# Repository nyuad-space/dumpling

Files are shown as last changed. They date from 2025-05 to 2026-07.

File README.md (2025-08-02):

## Hardware Errata v1 (2025)

- Pull down Boot1 instead of floating. For booting F405 with DFU, hold down the 3rd reset button.
- SWD TagConnect: Layout is too close to XT30 or M.2 sockets and connector is difficult to source.
- DRC check (recheck unconnected items).
- Look out for "x"ed POS in the BOM file. May have been accidentally toggled off.
- Reset button is too small & hard to reach
- Vertical USB is less stress-tolerant (pulls on solder)
- STM32F411 DFU bootloading error
- Check forward current rating for Schottky diodes.
- Consider using more current sensors i.e. Measure current draw from each board, from VIN total etc.
- Add in extra LEDs, buttons, etc. for extra functions/debugging in the future
- Unless saving space is a priority, consider using 0603 instead of 0402 for easier potential fixes
- Misc. Consider a more impact-tolerant casing to protect board upon landing

# Data Dumpling
<p float="left">
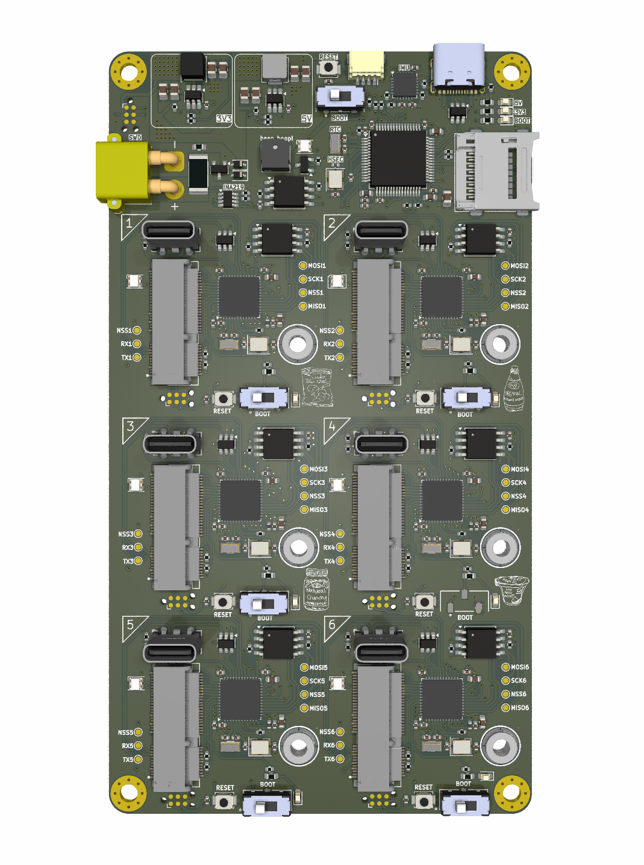
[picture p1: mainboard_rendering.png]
  
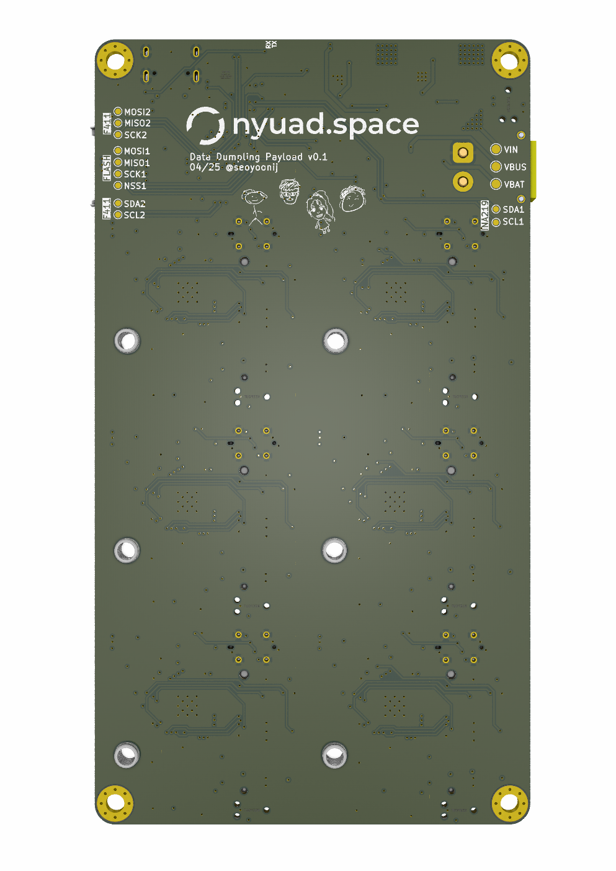
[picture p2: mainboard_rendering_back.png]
  
</p>

Data Dumpling is a modular, high-speed data logger for MEMS sensors, designed as a payload for our experimental sounding rocket Stage Fright (2025). It enables real-time characterization and benchmarking of commercial sensors in demanding flight environments. The project aims to support sensor research and promote scalable, plug-and-play architectures for future space missions.

---

## Features

- **Modular Architecture**: Hot-swappable M.2 sensor ports with dedicated coprocessors  
- **Sensor Compatibility**: Supports I2C/SPI sensors with auto-detection via WHO_AM_I or equivalent registers  
- **Dedicated Flash Memory**: Each sensor board logs to onboard 16MB non-volatile memory  
- **Universal Firmware**: One firmware for all sensor types—detects, initializes, logs, and stores automatically  
- **Flight-Triggered Logging**: Dual-buffered flash logging triggered by flight detection events  
- **Core MCU**: STM32F405 manages flight readiness and triggers; STM32F411 handles individual sensor boards  
- **Post-Flight Retrieval**: Optionally offloads sensor data to SD card after recovery  

---

## Applications

- Benchmarking MEMS sensors in realistic aerospace environments  
- Development of sensor fusion algorithms and accurate sensor models  
- Modular data collection for experimental payloads  
- Plug-and-play architecture for custom flight computers and high-speed telemetry systems  

---

## Mainboard Components

| Type | Components |
|---|---|
| Main MCU | STM32F405RGT |
| Coprocessor | STM32F411CEU6 |
| IMUs | LSM6DSO32, BMI088 |
| Barometers  | DPS310XTSA1, BMP390L |
| Magnetometer| LIS2MDLTR |
| Temperature | HDC3022DEJR |
| Flash | 16MB SPI NOR Flash per sensor board |
| Recovery | SD card slot for post-flight data offload |

---

## Firmware Overview

Each STM32 microcontroller is programmed via built-in USB DFU bootloader.

### Main processor
- Communicates with MPU6050 to determine upright position
- Triggers flight monitoring upon launch detection
- Manages three flash files:
  - **Circular Buffer**: Logs during flight-ready state with overwrite on overflow  
  - **Main Buffer**: Logs during flight, no wrap-around  
  - **Status File**: Logs sensor configuration, buffer states, memory info, etc.  

### Coprocessor
Each sensor board follows this universal sequence:

1. Detect sensor using WHO_AM_I (or equivalent)  
2. Initialize I2C or SPI communication  
3. Configure sensor parameters (range, ODR, oversampling, filters)  
4. Initialize filesystem and create sensor-specific files  
5. Log sensor data at configured rate to flash memory  

---

## Future Improvements

- Integrate RTOS for multitasking, task prioritization, and modular firmware structure
- Add wireless/CAN telemetry  
- Increase flash capacity and add compression  
- Expand to include GNSS, radiation, and vibration sensors  
- Enable real-time in-flight filtering and basic analytics
- Use UART for master-slave communication in Arduino framework (SPI doesn't support it by default)
- Ensure unique flash IDs and file headers per sensor for proper data parsing

---

## Notes

- Designed for SRAD rocketry — ensure proper mechanical and EMI shielding  
- Verify sensor electrical compatibility before connecting new boards  
- Maintain synchronized firmware versions across all sensor modules  
- Follow proper ESD precautions during handling and flashing  

---

## Disclaimer

Use the files, hardware, and software in this repository at your own risk.  
We assume no liability for hardware damage, software malfunction, or unexpected behavior, particularly during live flight testing.  
Always validate your configuration through extensive ground testing.

---

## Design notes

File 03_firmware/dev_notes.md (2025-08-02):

// event flow logic

<flash_readwrite.cpp>
TODO: add logic for after running out of storage for regular logging
v- Question: can i merge getSensorFilename into getSensorFileInfo? Also, why is that function not used anywhere?

<main.cpp>
// TODO: LED indication for circular/ regular logging etc.
// TODO: consider edge cases
// TODO: separate project for reading from flash 
v- // TODO: for attachInterrupt, instead of CHANGE, stick to either falling/rising edge
// TODO: circular is only writing header and not data. check write to circular logic again

// TODO: how to make sure flash is clean state before logging data

<new>
// third status log file
// F411 LED for circular/regular 
// fix HDC302 reading zeros

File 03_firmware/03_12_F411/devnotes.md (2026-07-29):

# Notes
1. Using classes 
- when the module owns a hardware device (FlashLogger, LSM6DSOnode, etc.)
- carries related objects' states together
- carries initialize and runtime methods together

2. New pipeline: Visualize data
- (Debug) Live serial mode: F411 sensor -> USB serial CSV stream -> Py app -> live plots + CSV save
- (Post-flight) Playback mode:                 -> saved CSV file -> Py app -> replay plot

# Errata
- Add telemetry (LoRa breakout) for real-time data visualization 
  (current: save to onboard flash- export over usb serial- app saves .csv to pc- app loads for playback)
- 

# TODO
- one firmware for both logging and export (controlled by F405?)

# TODO (immediate)
- Finalize F411:
  - batched/timed flush
  - integrity check for export: size/checksum validation
  - how to not seek EOF every sample when appending

  # TODO F405

  Recommended practical split:

F411 finalization sprint (short):
add drop/error counters
change flush strategy to batched or timed flush
add one integrity check for export
F405 start immediately in parallel:
RTOS task partition
launch-stage state machine
logger task with queue-based ingestion compatible with current schema

turn this into a concrete F405 task breakdown next (task list with module boundaries and suggested RTOS task rates/priorities).

F405 main functions:
- Communicates with MPU6050 (main IMU) to determine upright position- 
- Triggers flight monitoring upon launch detection
- Manages three flash files:
- **Circular Buffer**: Logs during flight-ready state with overwrite on overflow
- **Main Buffer**: Logs during flight, no wrap-around
- **Status File**: Logs sensor configuration, buffer states, memory info, etc.

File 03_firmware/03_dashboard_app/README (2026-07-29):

# dumpling Dashboard app

This app supports two modes:
1. **Live serial mode**
   F411 sensor data -> (USB serial) -> CSV samples -> live plotting + save CSV on pc
2. **Playback mode**
   F411 sensor data -> save CSV to flash -> upon recovery loads a CSV file -> replay + plot

## Serial format
e.g.
```text
timestamp_ms,ax_mps2,ay_mps2,az_mps2,gx_rads,gy_rads,gz_rads,temp_c
1840,2.843,-2.690,9.543,-0.001,0.001,-0.027,24.465
1850,2.851,-2.694,9.549,-0.002,0.001,-0.028,24.465
```

No extra debug text in the stream in ``SerialOutMode::Csv``

## User guide

From this directory, install:

```bash
pip install -r requirements.txt
```
n.b. Can't open both PlatformIO serial monitor and Python app at the same time- close one. 

1. Live serial mode
   - Upload only (not Monitor) with ``MODE = OperatingMode::LiveCsv;`` (and ctrl+C)
   - close serial monitor
   - find port: `` ls /dev/tty.*`` or ``ls /dev/cu.*``. If multiple, plug/unplug and see what appears/disappears.
      (e.g. ``/dev/tty.usbmodem2067379833311``)
   - then run: 
```bash
python app.py live --port /dev/tty.(usbmodem-port) --baud 115200 --save (filename).csv
```
``python app.py live --port /dev/tty.usbmodem2067379833311 --baud 115200 --save demo.csv``

===FOR DEBUG: no GUI ver.===
``python3 get_csv_wo_plot.py --port /dev/tty.usbmodem2067379833311 --baud 115200 --out noplot.csv``
``python3 plot_csv_simple.py --file noplot.csv``

On Windows, port names look like:
```bash
python app.py live --port COM5 --baud 115200 --save (filename).csv
```

2. Playback mode
Flash with ``MODE = OperatingMode::ExportLog;``, 
```bash
python export_log.py --port /dev/tty.usbmodem123 --baud 115200 --out (filename).csv

```
Or simply:
```bash
python app.py playback
```
and select a file in the file picker.

## Notes

- The live app saves every received sample to CSV.
- Playback mode uses the same CSV format.
- For best results, run the firmware with a clean machine-readable serial stream mode.

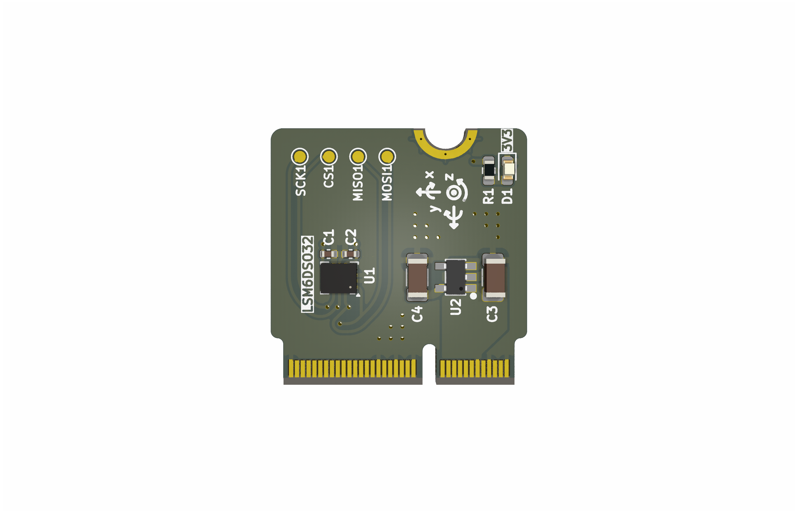
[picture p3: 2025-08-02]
02_sensor-board/sensorboard_rendering.png

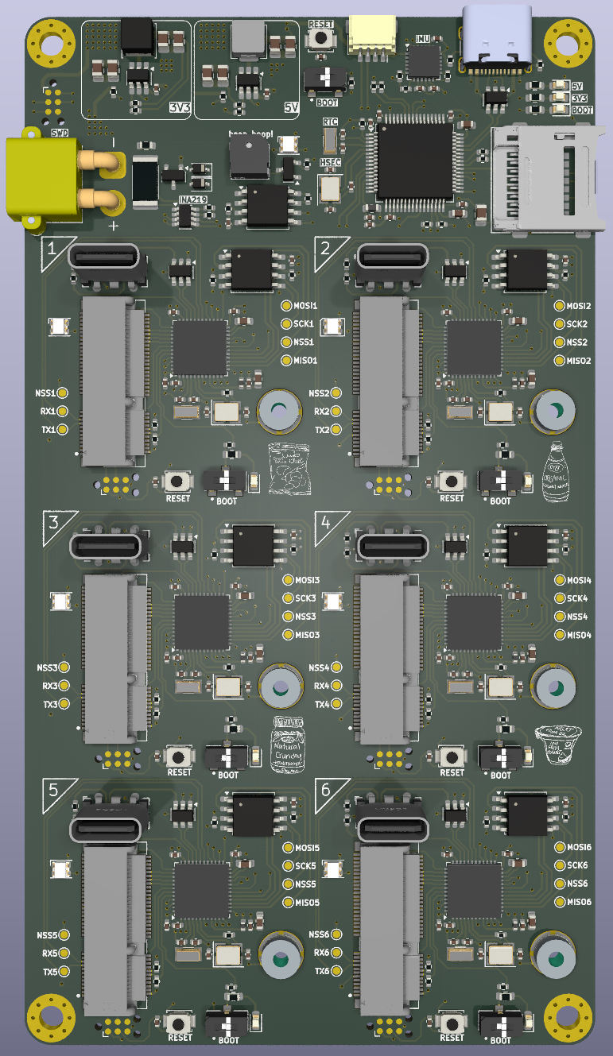
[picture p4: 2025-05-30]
01_main-board/Dumpling_Main.png

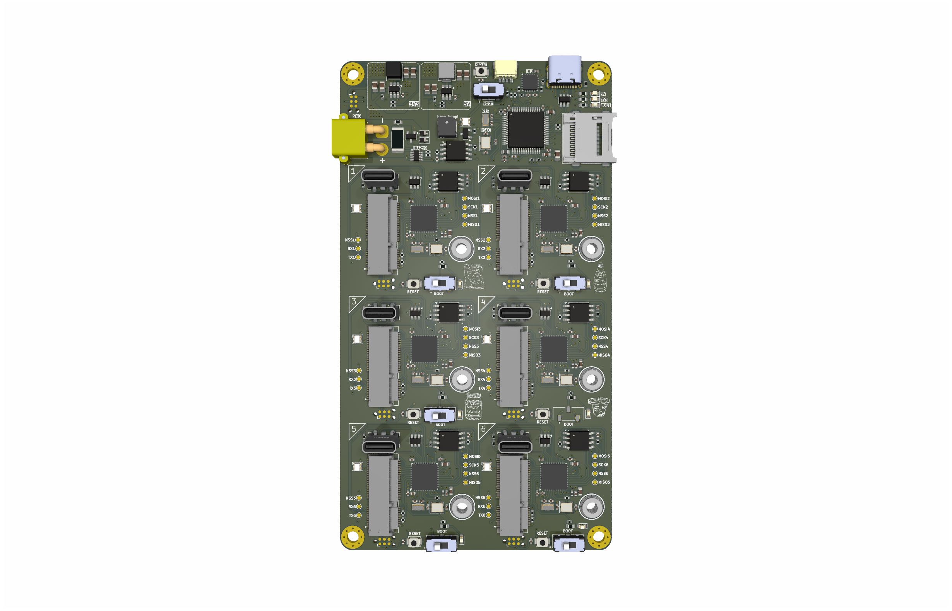
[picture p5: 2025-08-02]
01_main-board/mainboard_rendering.png

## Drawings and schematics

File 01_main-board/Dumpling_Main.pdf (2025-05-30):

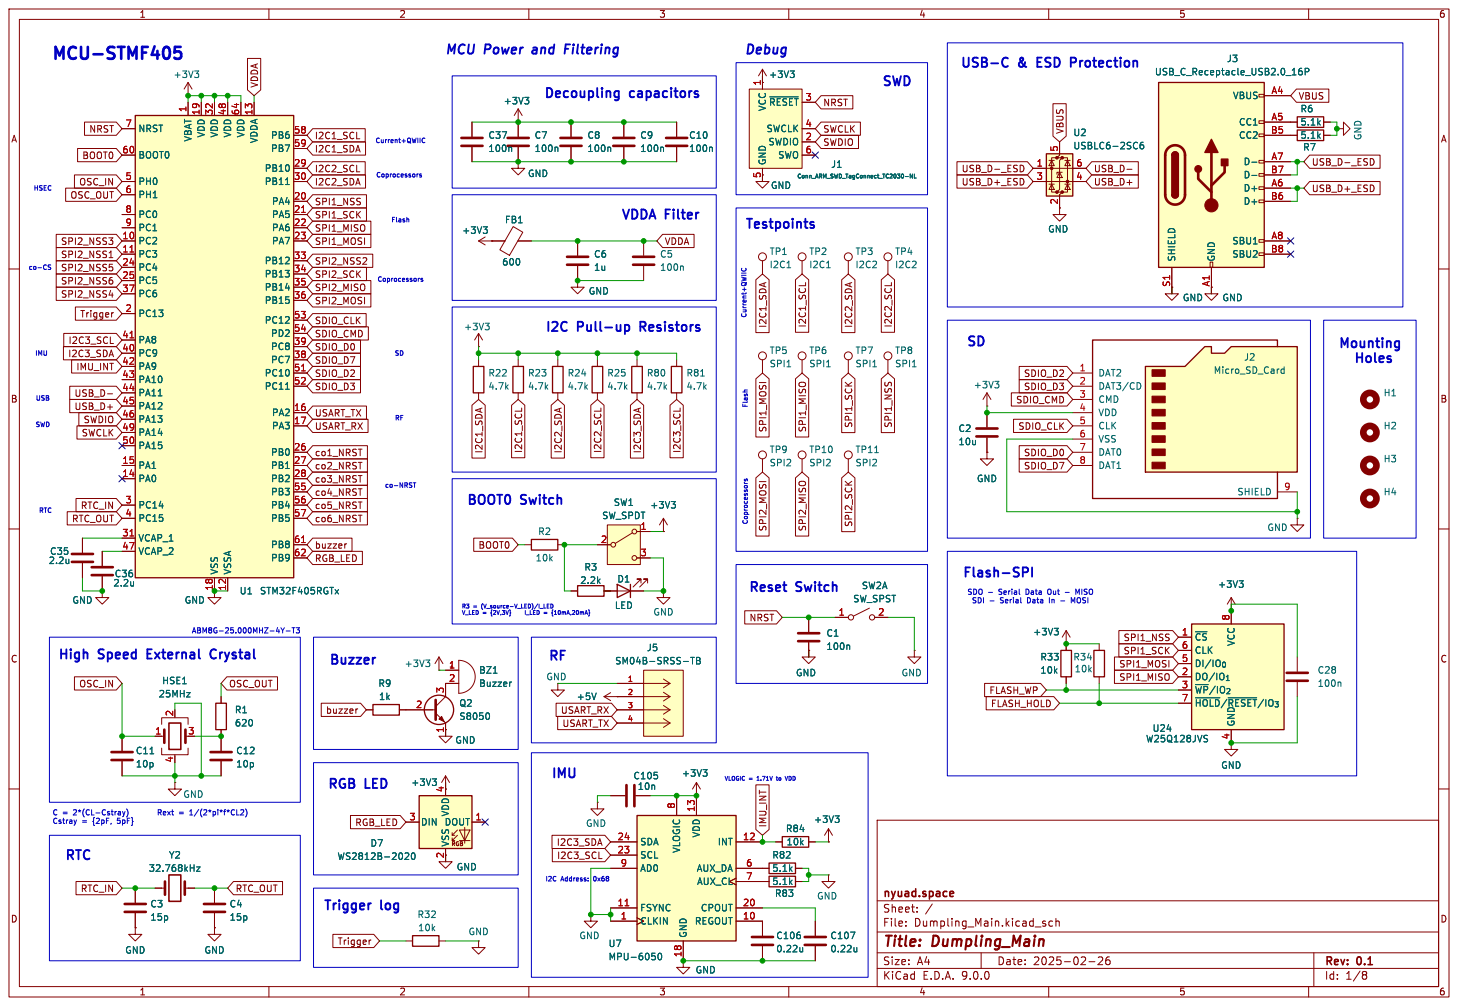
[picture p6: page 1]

MCU Power and Filtering

5 ~{RESET}3 SWCLK 4 SWDIO 2 SWO 6

5 ~{RESET}3 SWCLK 4 SWDIO 2 SWO 6 GND GND

1 VDD 19 VDD 32 VSS 18 VDD 48 VSSA 12 VDD 64 VDDA 13 PB6 58 PB7 59 PB10 29 PB11 30 PA4 20 PA5 21 PA6 22 PA7 23 PB12 33 PB13 34 PB14 35 PB15 36 PC12 53 PD2 54 PC8 39 PC7 38 PC10 51 PC11 52 PA2 16 PA3 17 PB0 26 PB1 27 PB2 28 PB3 55 PB4 56 PB5 57 PB8 61 PB9 C35 62

1 VDD 19 VDD 32 VSS 18 VDD 48 VSSA 12 VDD 64 VDDA 13 PB6 58 PB7 59 PB10 29 PB11 30 PA4 20 PA5 21 PA6 22 PA7 23 PB12 33 PB13 34 PB14 35 PB15 36 PC12 53 PD2 54 PC8 39 PC7 38 PC10 51 PC11 52 PA2 16 PA3 17 PB0 26 PB1 27 PB2 28 PB3 55 PB4 56 PB5 57 PB8 61 PB9 62 U1 STM32F405RGTx 1

NRST
Current+QWIIC High Speed External Crystal

VLOGIC = 1.71V to VDD Current+QWIIC

Flash-SPI SDO - Serial Data Out - MISO

File: Dumpling_Main.kicad_sch Sheet: / nyuad.space

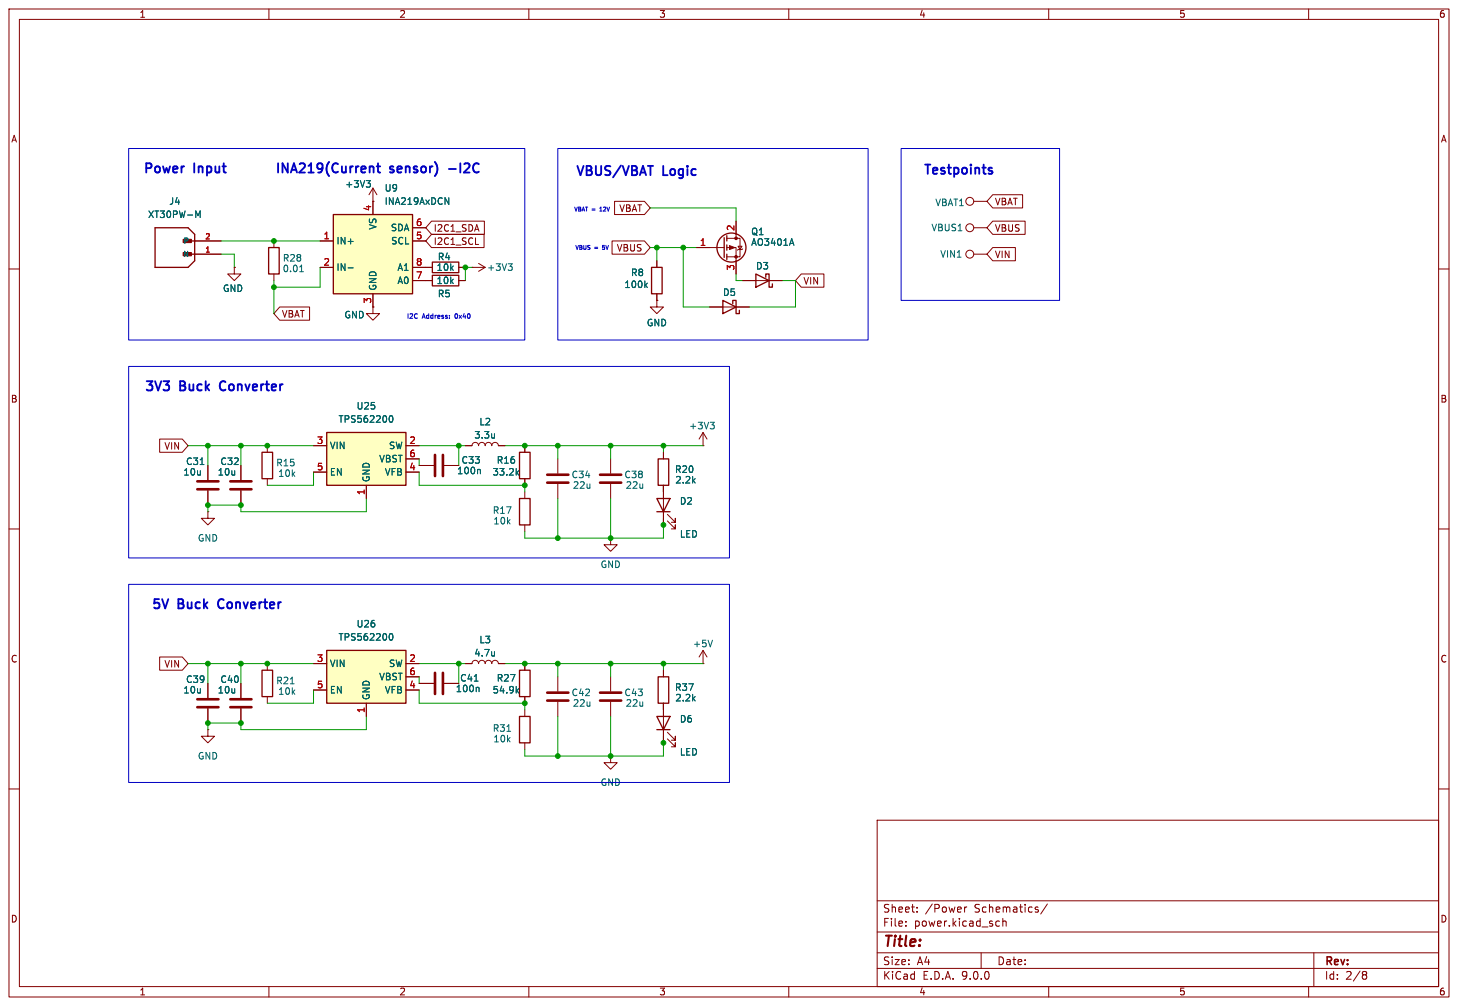
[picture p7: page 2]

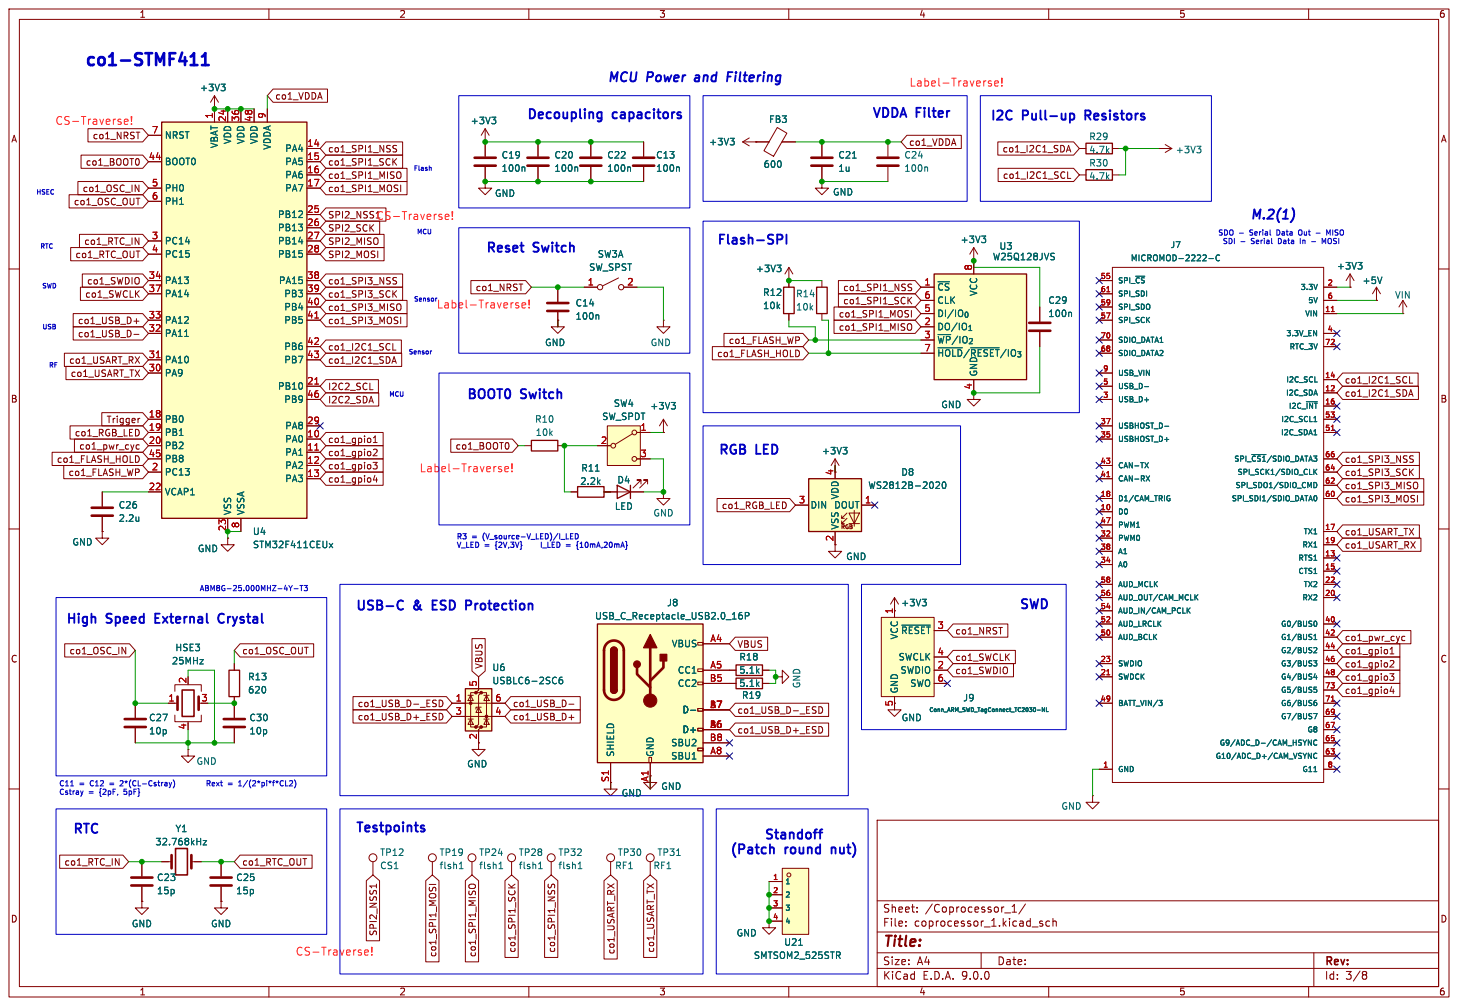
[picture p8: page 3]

MCU Power and Filtering
co1_USB_D- co1_BOOT0

1 VDD 24 VSS 23 VDD 36 VSSA

SDO - Serial Data Out - MISO

5 ~{RESET}3 SWCLK 4 SWDIO 2 SWO 6 R11

5 ~{RESET}3 SWCLK 4 SWDIO 2 SWO 6

Id: 3/8 Title: File: coprocessor_1.kicad_sch Sheet: /Coprocessor_1/

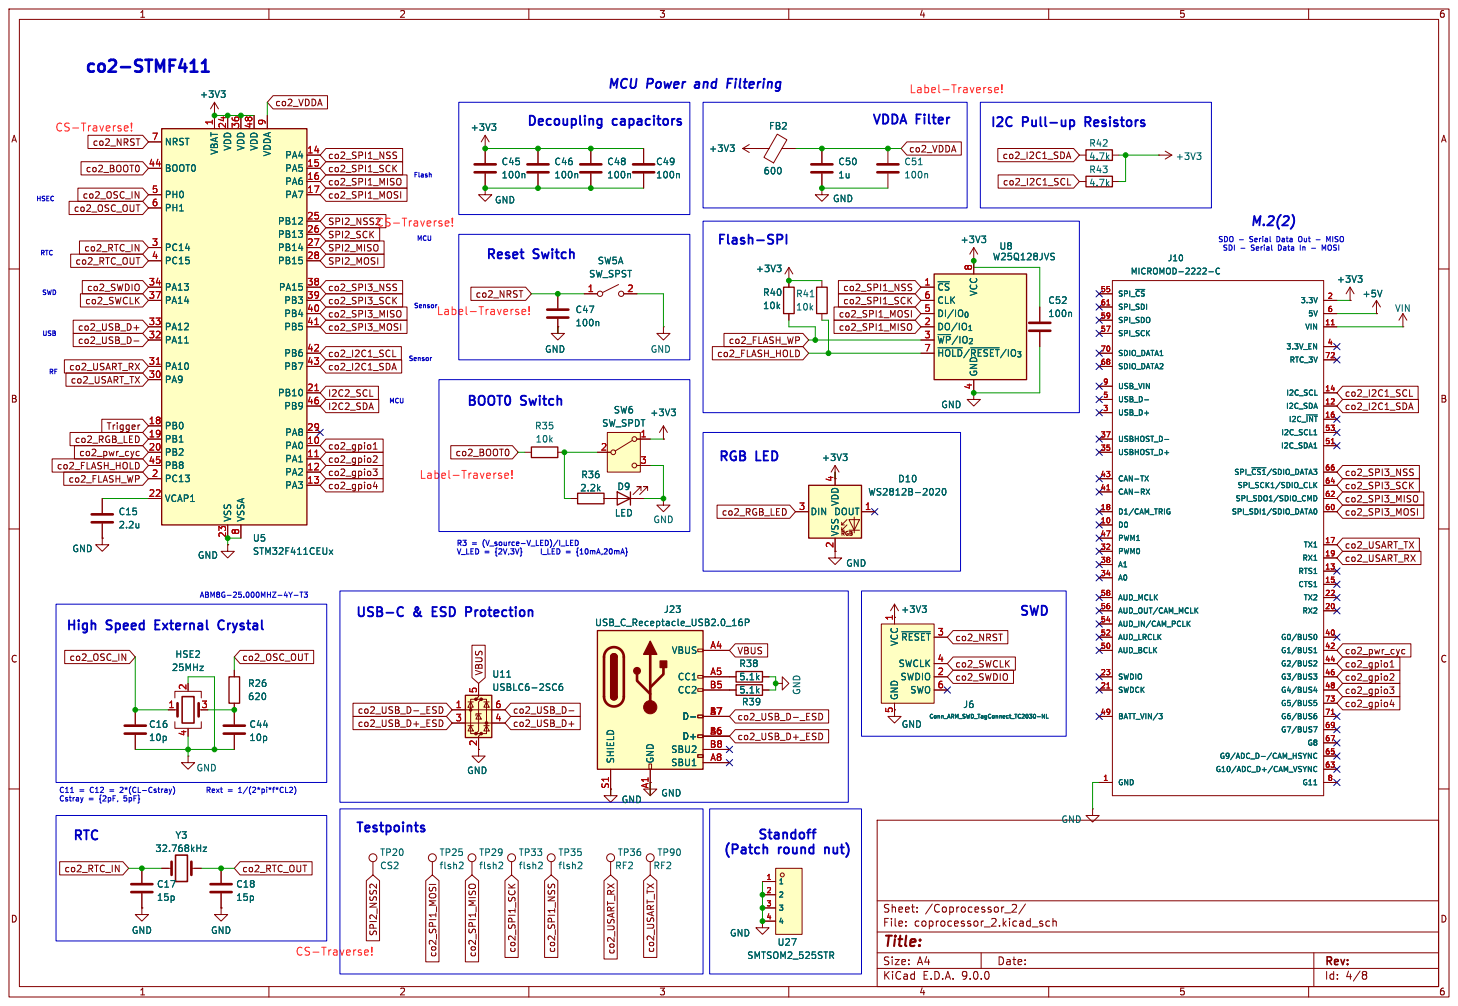
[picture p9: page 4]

1 VDD 24 VSS 23 VDD 36 VSSA
co2_SPI1_MOSI co2_I2C1_SCL

SDI - Serial Data In - MOSI Sensor Flash CS-Traverse!

5 ~{RESET}3 SWCLK 4 SWDIO 2 SWO 6 +3V3 GND

5 ~{RESET}3 SWCLK 4 SWDIO 2 SWO 6

Id: 4/8 Title: File: coprocessor_2.kicad_sch Sheet: /Coprocessor_2/

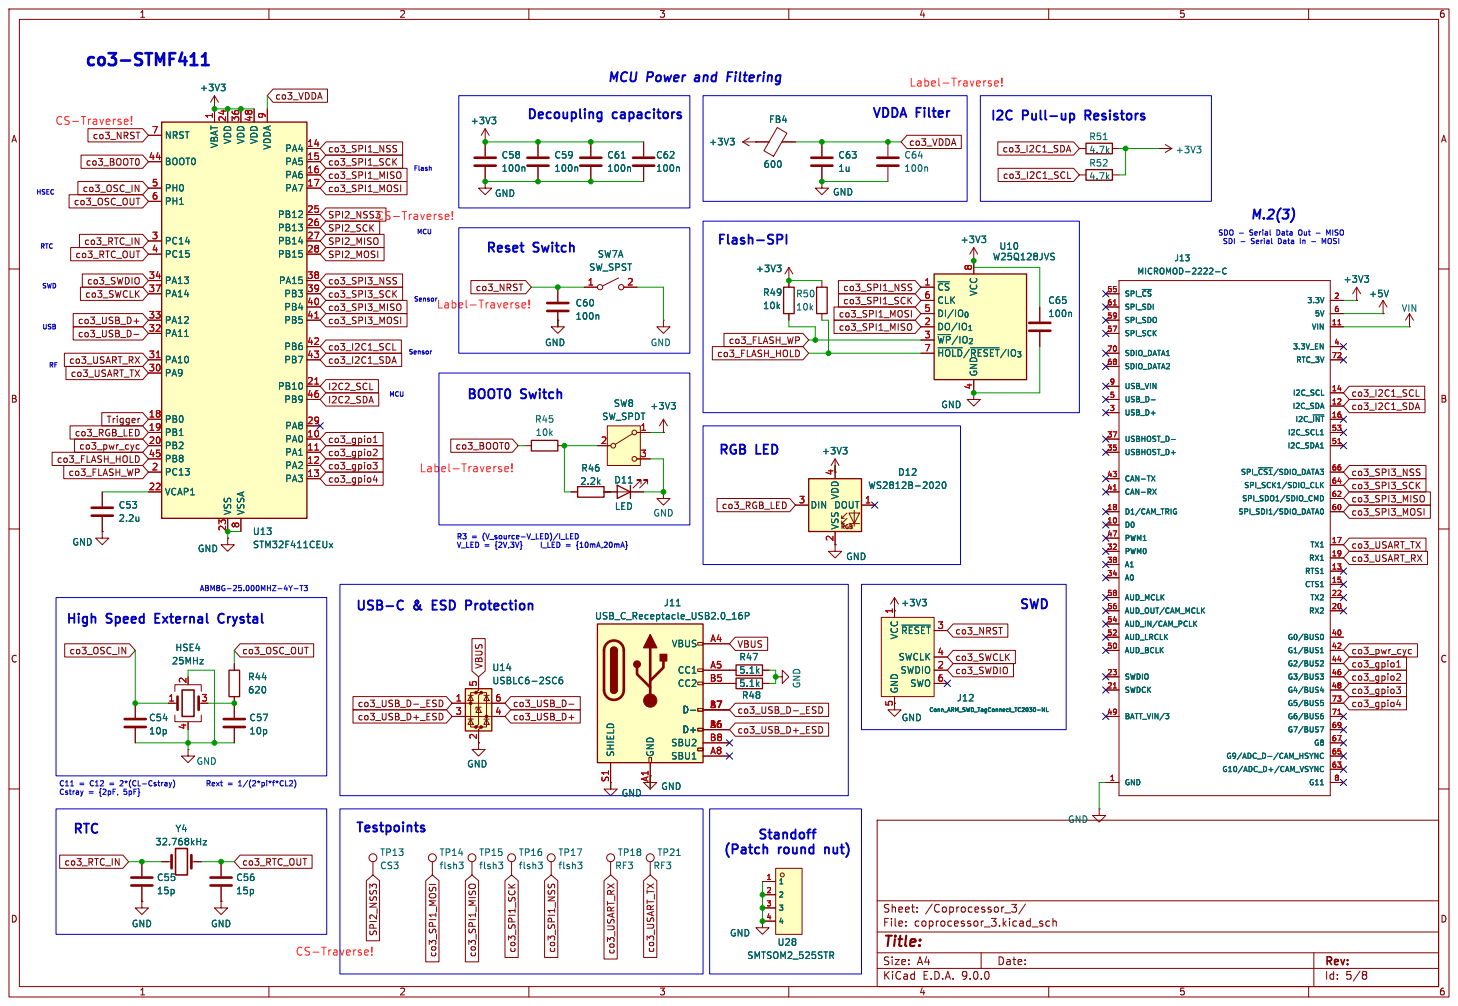
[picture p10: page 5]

1 VDD 24 VSS 23 VDD 36 VSSA

SDI - Serial Data In - MOSI MCU Testpoints

High Speed External Crystal

5 ~{RESET}3 SWCLK 4 SWDIO 2 SWO 6

Id: 5/8 Title: File: coprocessor_3.kicad_sch Sheet: /Coprocessor_3/ R44

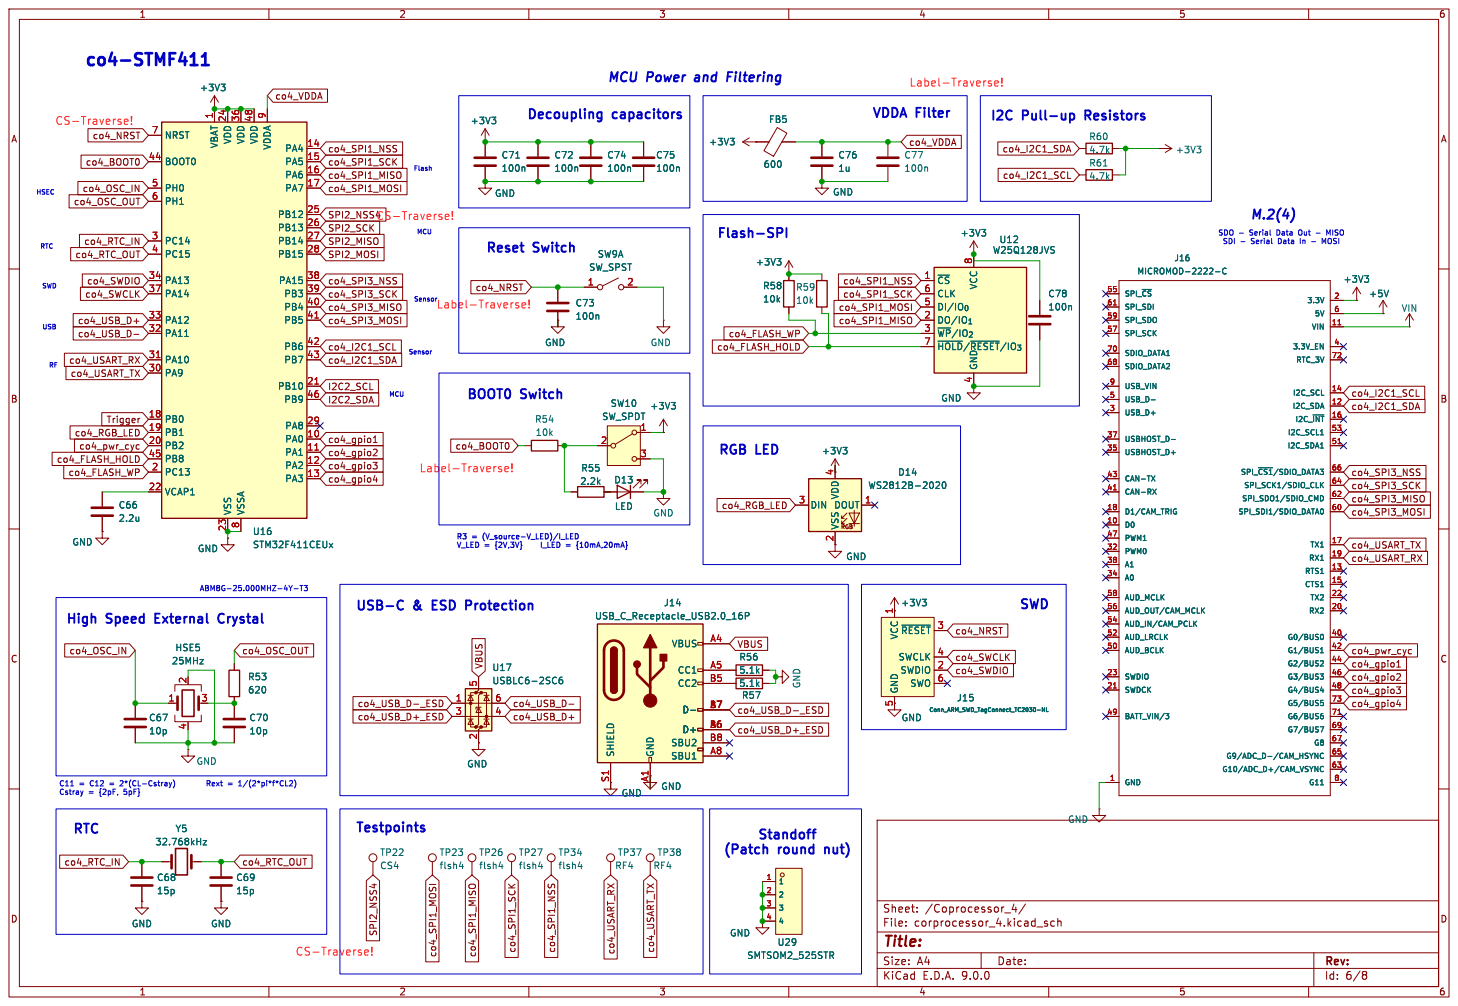
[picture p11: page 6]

SDI - Serial Data In - MOSI CS-Traverse!

1 VDD 24 VSS 23 VDD 36 VSSA

M.2(4) SDO - Serial Data Out - MISO

5 ~{RESET}3 SWCLK 4 SWDIO 2 SWO 6 +3V3 GND GND

5 ~{RESET}3 SWCLK 4 SWDIO 2 SWO 6

Id: 6/8 Title: File: corprocessor_4.kicad_sch Sheet: /Coprocessor_4/

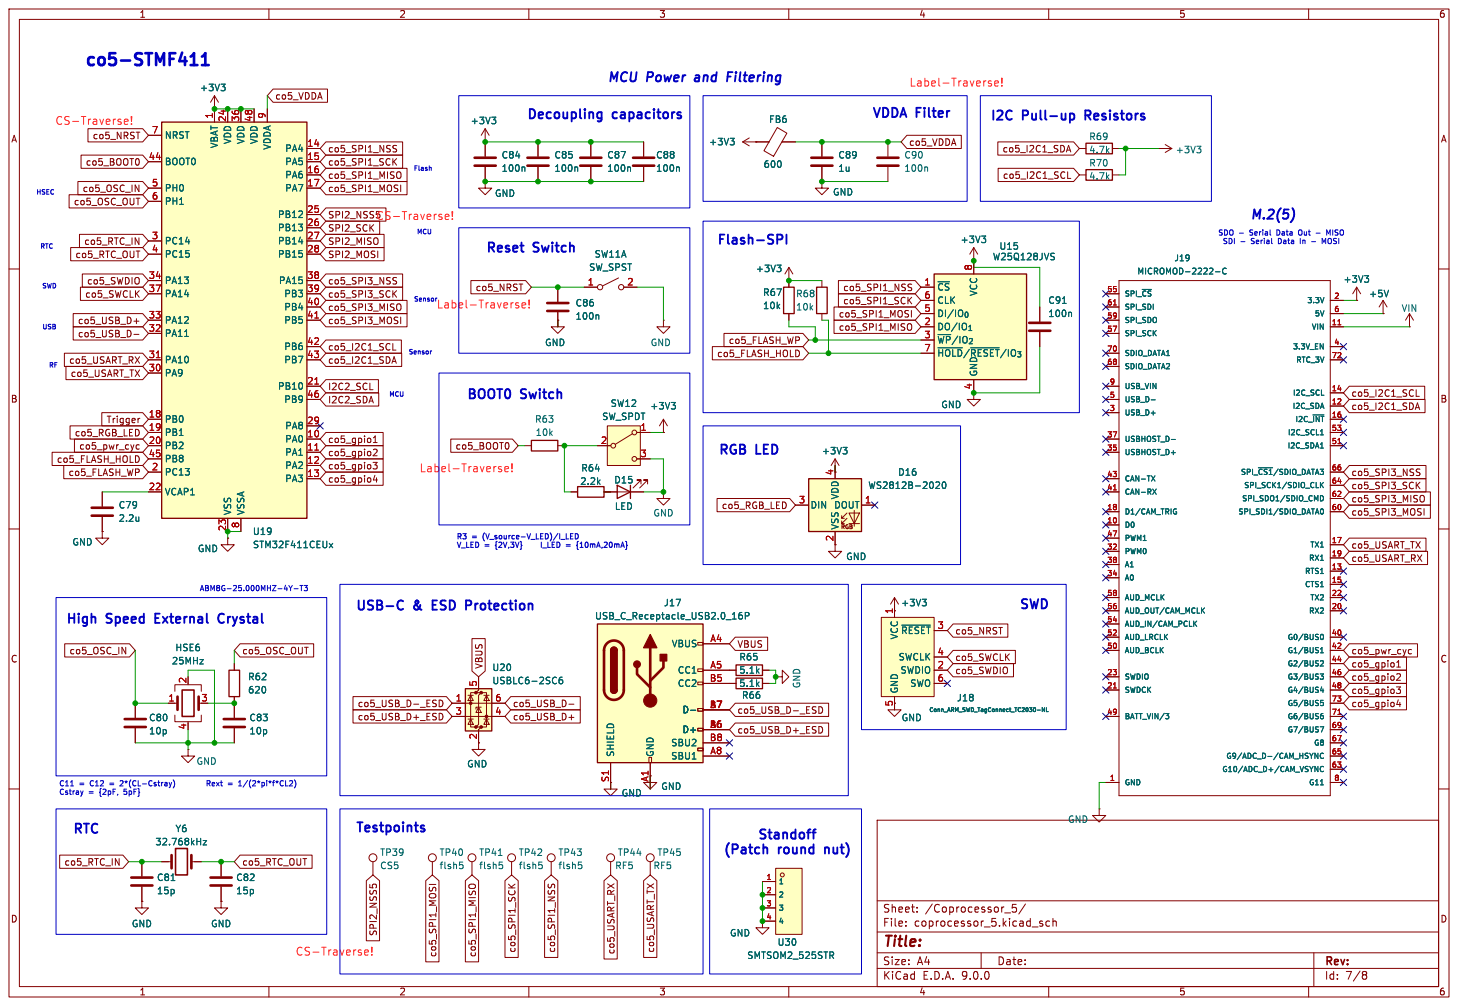
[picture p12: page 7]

MCU Power and Filtering

1 VDD 24 VSS 23 VDD 36 VSSA
2.2k GND

co5_OSC_IN
Sensor Sensor MCU ABM8G-25.000MHZ-4Y-T3 CS-Traverse!

SDI - Serial Data In - MOSI M.2(5)

High Speed External Crystal

5 ~{RESET}3 SWCLK 4 SWDIO 2 SWO 6

5 ~{RESET}3 SWCLK 4 SWDIO 2 SWO 6 GND

Id: 7/8 Title: File: coprocessor_5.kicad_sch Sheet: /Coprocessor_5/

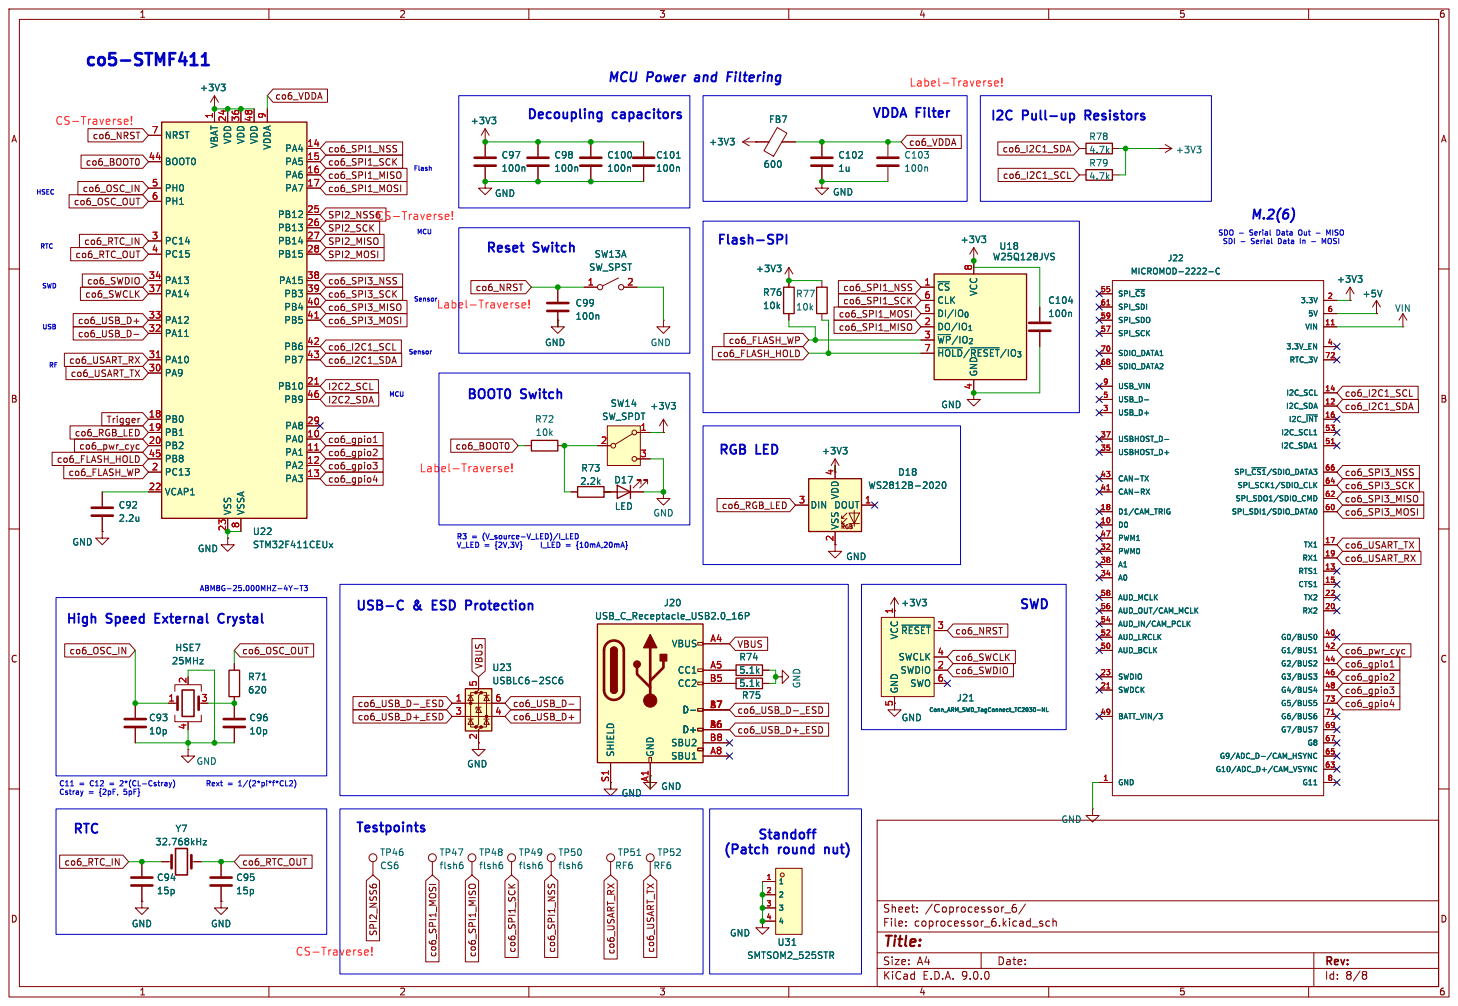
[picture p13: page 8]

1 VDD 24 VSS 23 VDD 36 VSSA
co6_BOOT0 Trigger

SDI - Serial Data In - MOSI Reset Switch

High Speed External Crystal

5 ~{RESET}3 SWCLK 4 SWDIO 2 SWO 6

5 ~{RESET}3 SWCLK 4 SWDIO 2 SWO 6 GND

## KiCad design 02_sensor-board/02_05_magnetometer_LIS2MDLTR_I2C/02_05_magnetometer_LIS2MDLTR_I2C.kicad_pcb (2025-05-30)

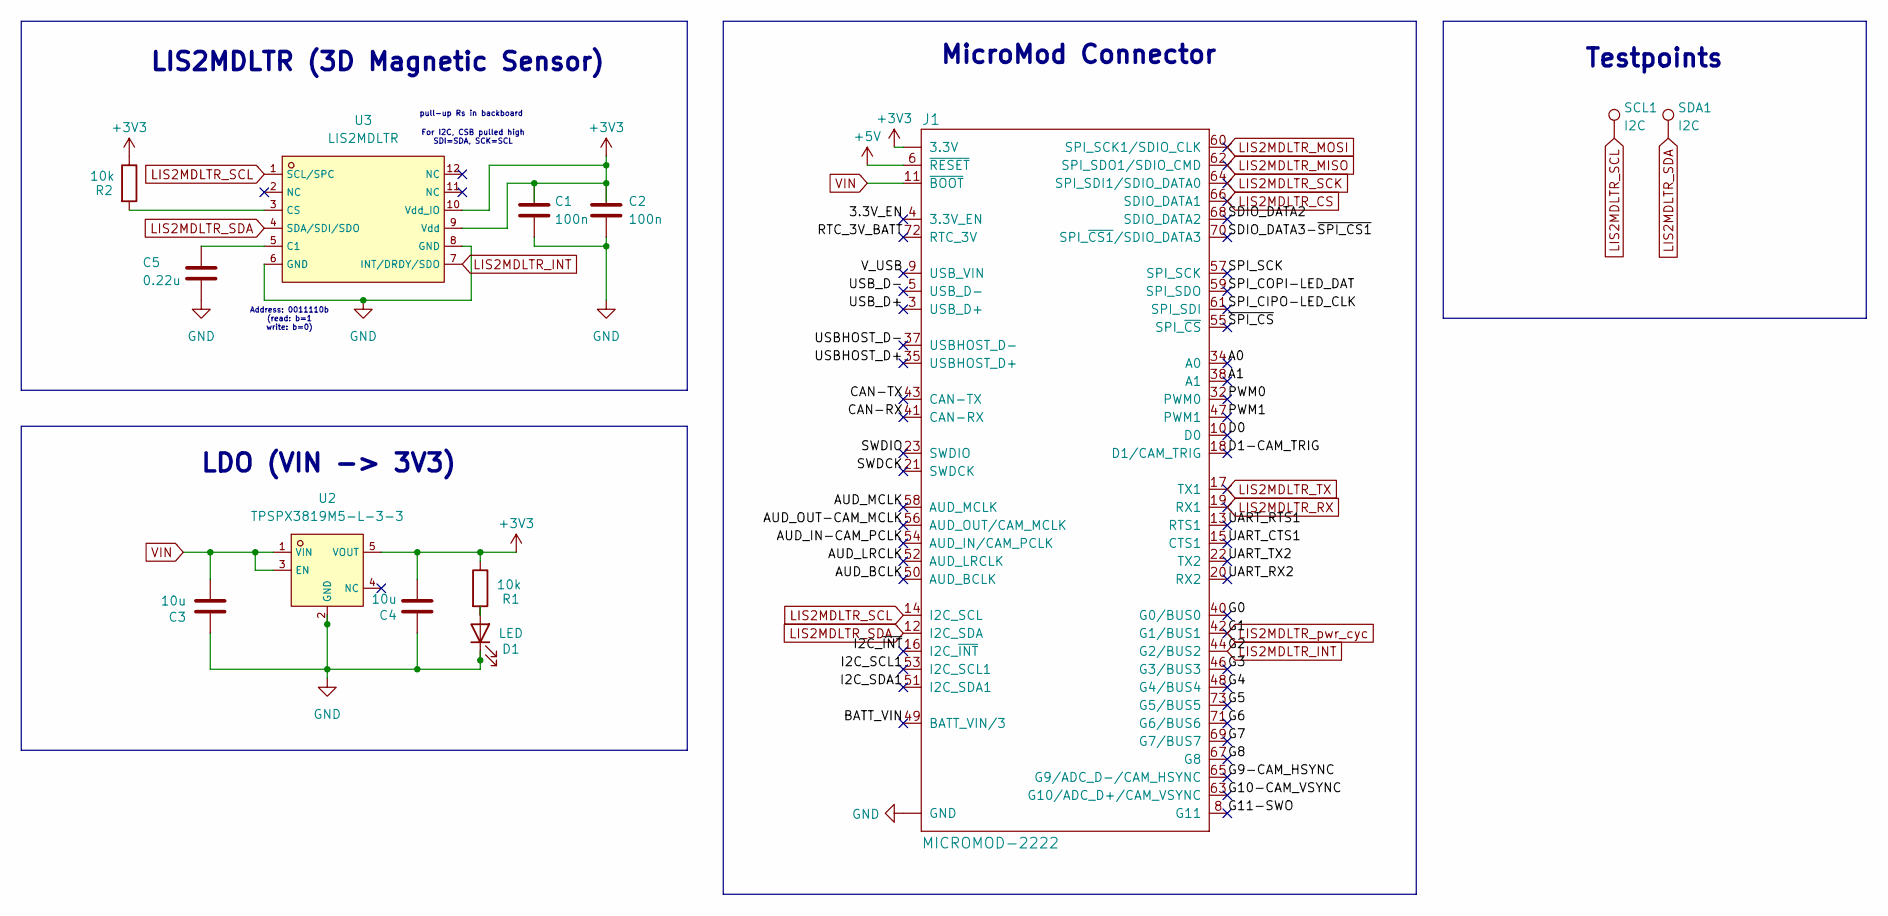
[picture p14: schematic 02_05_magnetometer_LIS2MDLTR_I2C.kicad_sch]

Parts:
C1, C2: 100n; C_0402_1005Metric
C3, C4: 10u; C_1206_3216Metric
C5: 0.22u; C_0402_1005Metric
D1: LED; LED_0603_1608Metric
J1: MICROMOD-2222; M.2-CARD-E-22
R1: 10k; R_0603_1608Metric
R2: 10k; R_0402_1005Metric
SCL1: I2C; TestPoint_Pad_D1.0mm
SDA1: I2C; TestPoint_Pad_D1.0mm
U2: TPSPX3819M5-L-3-3; SOT-23-5_L3.0-W1.6-P0.95-LS2.8-BR; LCSC C5370980
U3: LIS2MDLTR; LGA-12_L2.0-W2.0-P0.50-BL; LCSC C919695

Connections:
+3V3: C1.1, C2.1, C4.1, J1.2 (3.3V), J1.74 (3.3V), R1.1, R2.1, U2.5 (VOUT), U3.9 (Vdd), U3.10 (Vdd_IO)
+5V: J1.6 (~RESET)
/3.3V_EN: J1.4 (3.3V_EN)
/A0: J1.34 (A0)
/A1: J1.38 (A1)
/AUD_BCLK: J1.50 (AUD_BCLK)
/AUD_IN-CAM_PCLK: J1.54 (AUD_IN/CAM_PCLK)
/AUD_LRCLK: J1.52 (AUD_LRCLK)
/AUD_MCLK: J1.58 (AUD_MCLK)
/AUD_OUT-CAM_MCLK: J1.56 (AUD_OUT/CAM_MCLK)
/BATT_VIN: J1.49 (BATT_VIN/3)
/CAN-RX: J1.41 (CAN-RX)
/CAN-TX: J1.43 (CAN-TX)
/D0: J1.10 (D0)
/D1-CAM_TRIG: J1.18 (D1/CAM_TRIG)
/G0: J1.40 (G0/BUS0)
/G3: J1.46 (G3/BUS3)
/G4: J1.48 (G4/BUS4)
/G5: J1.73 (G5/BUS5)
/G6: J1.71 (G6/BUS6)
/G7: J1.69 (G7/BUS7)
/G8: J1.67 (G8)
/G9-CAM_HSYNC: J1.65 (G9/ADC_D-/CAM_HSYNC)
/G10-CAM_VSYNC: J1.63 (G10/ADC_D+/CAM_VSYNC)
/G11-SWO: J1.8 (G11)
/I2C_SCL1: J1.53 (I2C_SCL1)
/I2C_SDA1: J1.51 (I2C_SDA1)
/I2C_~INT: J1.16 (I2C_~INT)
/PWM0: J1.32 (PWM0)
/PWM1: J1.47 (PWM1)
/RTC_3V_BATT: J1.72 (RTC_3V)
/SDIO_DATA2: J1.68 (SDIO_DATA2)
/SDIO_DATA3-~SPI_CS1: J1.70 (SPI_~CS1/SDIO_DATA3)
/SPI_CIPO-LED_CLK: J1.61 (SPI_SDI)
/SPI_COPI-LED_DAT: J1.59 (SPI_SDO)
/SPI_SCK: J1.57 (SPI_SCK)
/SWDCK: J1.21 (SWDCK)
/SWDIO: J1.23 (SWDIO)
/UART_CTS1: J1.15 (CTS1)
/UART_RTS1: J1.13 (RTS1)
/UART_RX2: J1.20 (RX2)
/UART_TX2: J1.22 (TX2)
/USBHOST_D+: J1.35 (USBHOST_D+)
/USBHOST_D-: J1.37 (USBHOST_D-)
/USB_D+: J1.3 (USB_D+)
/USB_D-: J1.5 (USB_D-)
/V_USB: J1.9 (USB_VIN)
/~SPI_CS: J1.55 (SPI_~CS)
GND: C1.2, C2.2, C3.2, C4.2, C5.2, D1.1 (K), J1.1 (GND), J1.7 (GND), J1.33 (GND), J1.36 (GND), J1.39 (GND), J1.45 (GND), J1.75 (GND), J1.GND1 (GND), J1.GND2 (GND), J1.GND3 (GND), U2.2 (GND), U3.6 (GND), U3.8 (GND)
LIS2MDLTR_CS: J1.66 (SDIO_DATA1)
LIS2MDLTR_INT: J1.44 (G2/BUS2), U3.7 (INT/DRDY/SDO)
LIS2MDLTR_MISO: J1.62 (SPI_SDO1/SDIO_CMD)
LIS2MDLTR_MOSI: J1.60 (SPI_SCK1/SDIO_CLK)
LIS2MDLTR_RX: J1.19 (RX1)
LIS2MDLTR_SCK: J1.64 (SPI_SDI1/SDIO_DATA0)
LIS2MDLTR_SCL: J1.14 (I2C_SCL), SCL1.1, U3.1 (SCL/SPC)
LIS2MDLTR_SDA: J1.12 (I2C_SDA), SDA1.1, U3.4 (SDA/SDI/SDO)
LIS2MDLTR_TX: J1.17 (TX1)
LIS2MDLTR_pwr_cyc: J1.42 (G1/BUS1)
unnamed: D1.2 (A), R1.2
unnamed: C5.1, U3.5 (C1)
unnamed: R2.2, U3.3 (CS)
VIN: C3.1, J1.11 (~BOOT), U2.1 (VIN), U2.3 (EN)

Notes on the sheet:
pull-up Rs in backboard
Address: 0011110b (read: b=1 write: b=0)
MicroMod Connector
LDO (VIN -> 3V3)
LIS2MDLTR (3D Magnetic Sensor)
For I2C, CSB pulled high SDI=SDA, SCK=SCL
Testpoints

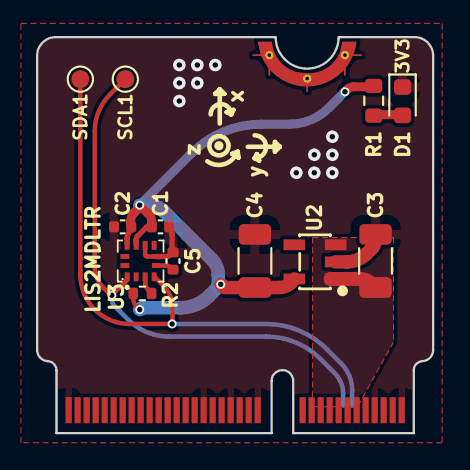
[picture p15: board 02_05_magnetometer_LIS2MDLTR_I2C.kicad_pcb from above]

Board: 2 copper layers, 22.0 x 22.0 mm, 15 parts (0 on the bottom side), 9 nets.

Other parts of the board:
FRAME1: FRAME-LEDGER; CREATIVE_COMMONS
LOGO1: SPECIAL_INSTRUCTIONS-ORDERING; ORDERING_INSTRUCTIONS

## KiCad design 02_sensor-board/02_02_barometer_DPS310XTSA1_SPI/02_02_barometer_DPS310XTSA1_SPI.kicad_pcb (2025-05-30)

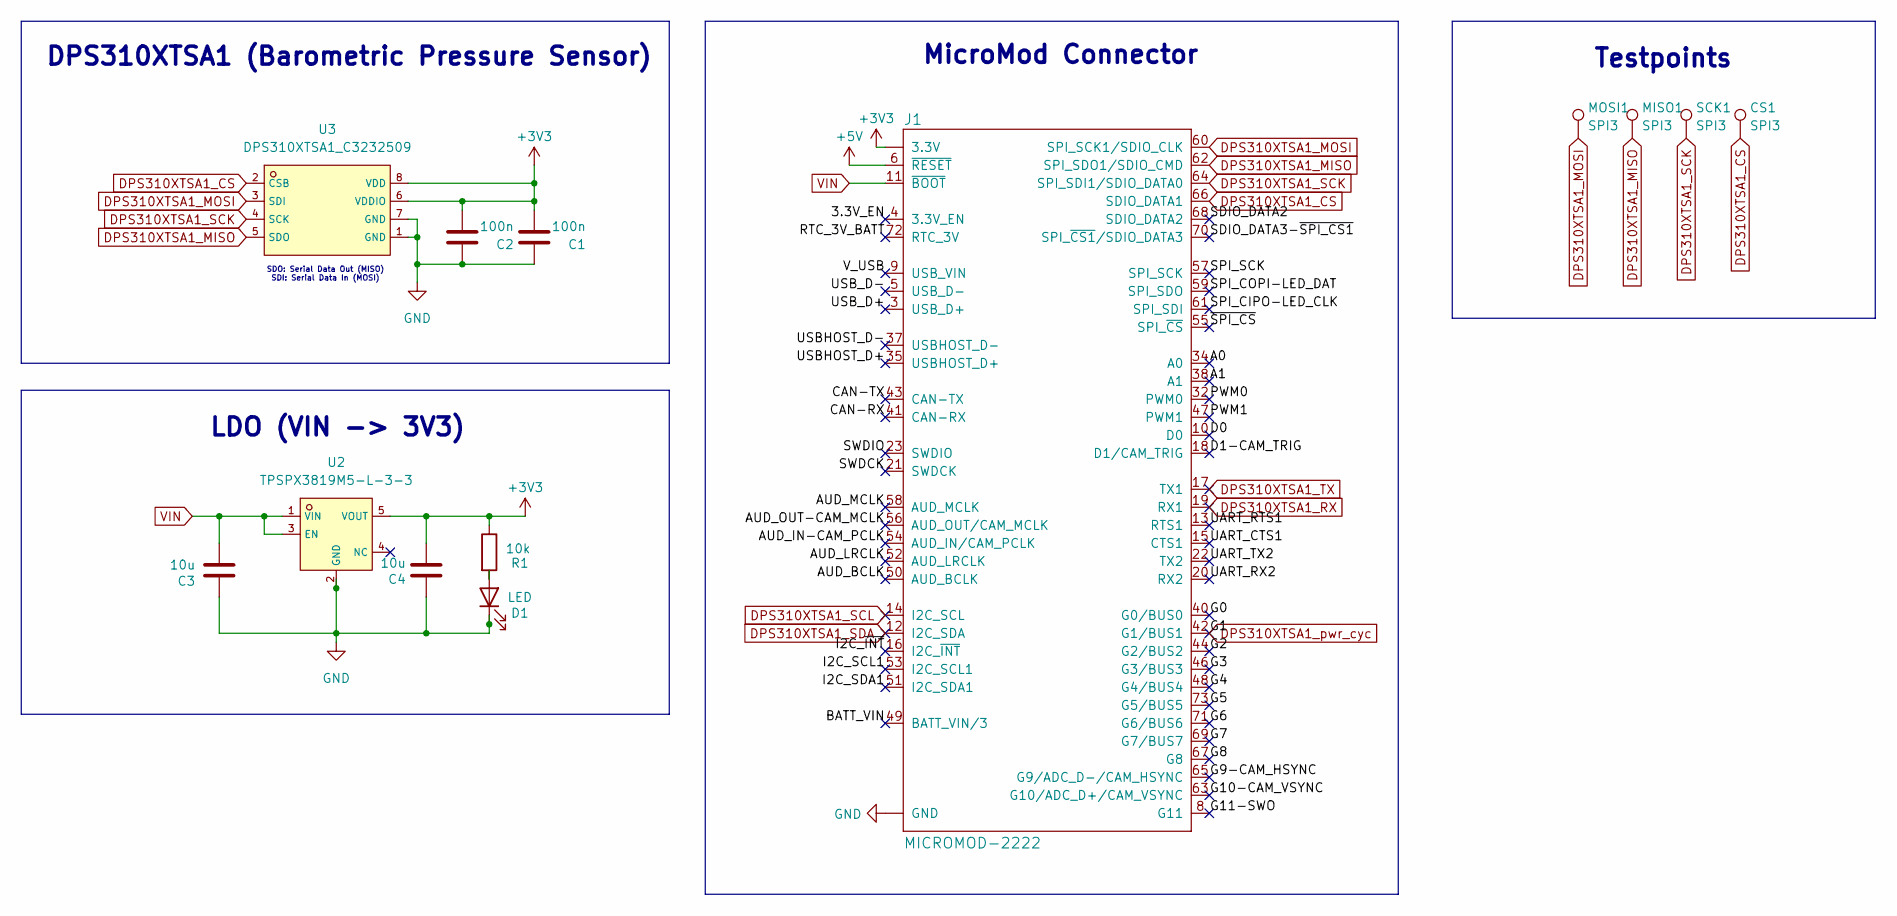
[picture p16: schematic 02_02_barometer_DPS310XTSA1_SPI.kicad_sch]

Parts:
C1, C2: 100n; C_0402_1005Metric
C3, C4: 10u; C_1206_3216Metric
CS1: SPI3; TestPoint_Pad_D1.0mm
D1: LED; LED_0603_1608Metric
J1: MICROMOD-2222; M.2-CARD-E-22
MISO1: SPI3; TestPoint_Pad_D1.0mm
MOSI1: SPI3; TestPoint_Pad_D1.0mm
R1: 10k; R_0603_1608Metric
SCK1: SPI3; TestPoint_Pad_D1.0mm
U2: TPSPX3819M5-L-3-3; SOT-23-5_L3.0-W1.6-P0.95-LS2.8-BR; LCSC C5370980
U3: DPS310XTSA1_C3232509; LGA-8_DPS310XTSA1; LCSC C3232509

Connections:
+3V3: C1.1, C2.1, C4.1, J1.2 (3.3V), J1.74 (3.3V), R1.1, U2.5 (VOUT), U3.6 (VDDIO), U3.8 (VDD)
+5V: J1.6 (~RESET)
/3.3V_EN: J1.4 (3.3V_EN)
/A0: J1.34 (A0)
/A1: J1.38 (A1)
/AUD_BCLK: J1.50 (AUD_BCLK)
/AUD_IN-CAM_PCLK: J1.54 (AUD_IN/CAM_PCLK)
/AUD_LRCLK: J1.52 (AUD_LRCLK)
/AUD_MCLK: J1.58 (AUD_MCLK)
/AUD_OUT-CAM_MCLK: J1.56 (AUD_OUT/CAM_MCLK)
/BATT_VIN: J1.49 (BATT_VIN/3)
/CAN-RX: J1.41 (CAN-RX)
/CAN-TX: J1.43 (CAN-TX)
/D0: J1.10 (D0)
/D1-CAM_TRIG: J1.18 (D1/CAM_TRIG)
/G0: J1.40 (G0/BUS0)
/G2: J1.44 (G2/BUS2)
/G3: J1.46 (G3/BUS3)
/G4: J1.48 (G4/BUS4)
/G5: J1.73 (G5/BUS5)
/G6: J1.71 (G6/BUS6)
/G7: J1.69 (G7/BUS7)
/G8: J1.67 (G8)
/G9-CAM_HSYNC: J1.65 (G9/ADC_D-/CAM_HSYNC)
/G10-CAM_VSYNC: J1.63 (G10/ADC_D+/CAM_VSYNC)
/G11-SWO: J1.8 (G11)
/I2C_SCL1: J1.53 (I2C_SCL1)
/I2C_SDA1: J1.51 (I2C_SDA1)
/I2C_~INT: J1.16 (I2C_~INT)
/PWM0: J1.32 (PWM0)
/PWM1: J1.47 (PWM1)
/RTC_3V_BATT: J1.72 (RTC_3V)
/SDIO_DATA2: J1.68 (SDIO_DATA2)
/SDIO_DATA3-~SPI_CS1: J1.70 (SPI_~CS1/SDIO_DATA3)
/SPI_CIPO-LED_CLK: J1.61 (SPI_SDI)
/SPI_COPI-LED_DAT: J1.59 (SPI_SDO)
/SPI_SCK: J1.57 (SPI_SCK)
/SWDCK: J1.21 (SWDCK)
/SWDIO: J1.23 (SWDIO)
/UART_CTS1: J1.15 (CTS1)
/UART_RTS1: J1.13 (RTS1)
/UART_RX2: J1.20 (RX2)
/UART_TX2: J1.22 (TX2)
/USBHOST_D+: J1.35 (USBHOST_D+)
/USBHOST_D-: J1.37 (USBHOST_D-)
/USB_D+: J1.3 (USB_D+)
/USB_D-: J1.5 (USB_D-)
/V_USB: J1.9 (USB_VIN)
/~SPI_CS: J1.55 (SPI_~CS)
DPS310XTSA1_CS: CS1.1, J1.66 (SDIO_DATA1), U3.2 (CSB)
DPS310XTSA1_MISO: J1.62 (SPI_SDO1/SDIO_CMD), MISO1.1, U3.5 (SDO)
DPS310XTSA1_MOSI: J1.60 (SPI_SCK1/SDIO_CLK), MOSI1.1, U3.3 (SDI)
DPS310XTSA1_RX: J1.19 (RX1)
DPS310XTSA1_SCK: J1.64 (SPI_SDI1/SDIO_DATA0), SCK1.1, U3.4 (SCK)
DPS310XTSA1_SCL: J1.14 (I2C_SCL)
DPS310XTSA1_SDA: J1.12 (I2C_SDA)
DPS310XTSA1_TX: J1.17 (TX1)
DPS310XTSA1_pwr_cyc: J1.42 (G1/BUS1)
GND: C1.2, C2.2, C3.2, C4.2, D1.1 (K), J1.1 (GND), J1.7 (GND), J1.33 (GND), J1.36 (GND), J1.39 (GND), J1.45 (GND), J1.75 (GND), J1.GND1 (GND), J1.GND2 (GND), J1.GND3 (GND), U2.2 (GND), U3.1 (GND), U3.7 (GND)
unnamed: D1.2 (A), R1.2
VIN: C3.1, J1.11 (~BOOT), U2.1 (VIN), U2.3 (EN)

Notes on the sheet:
SDO: Serial Data Out (MISO) SDI: Serial Data In (MOSI)
DPS310XTSA1 (Barometric Pressure Sensor)
MicroMod Connector
LDO (VIN -> 3V3)
Testpoints

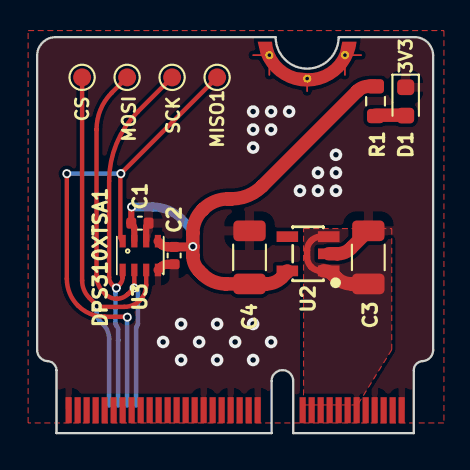
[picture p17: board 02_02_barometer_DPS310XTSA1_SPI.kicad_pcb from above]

Board: 2 copper layers, 22.0 x 22.0 mm, 15 parts (0 on the bottom side), 8 nets.

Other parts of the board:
FRAME1: FRAME-LEDGER; CREATIVE_COMMONS
LOGO1: SPECIAL_INSTRUCTIONS-ORDERING; ORDERING_INSTRUCTIONS

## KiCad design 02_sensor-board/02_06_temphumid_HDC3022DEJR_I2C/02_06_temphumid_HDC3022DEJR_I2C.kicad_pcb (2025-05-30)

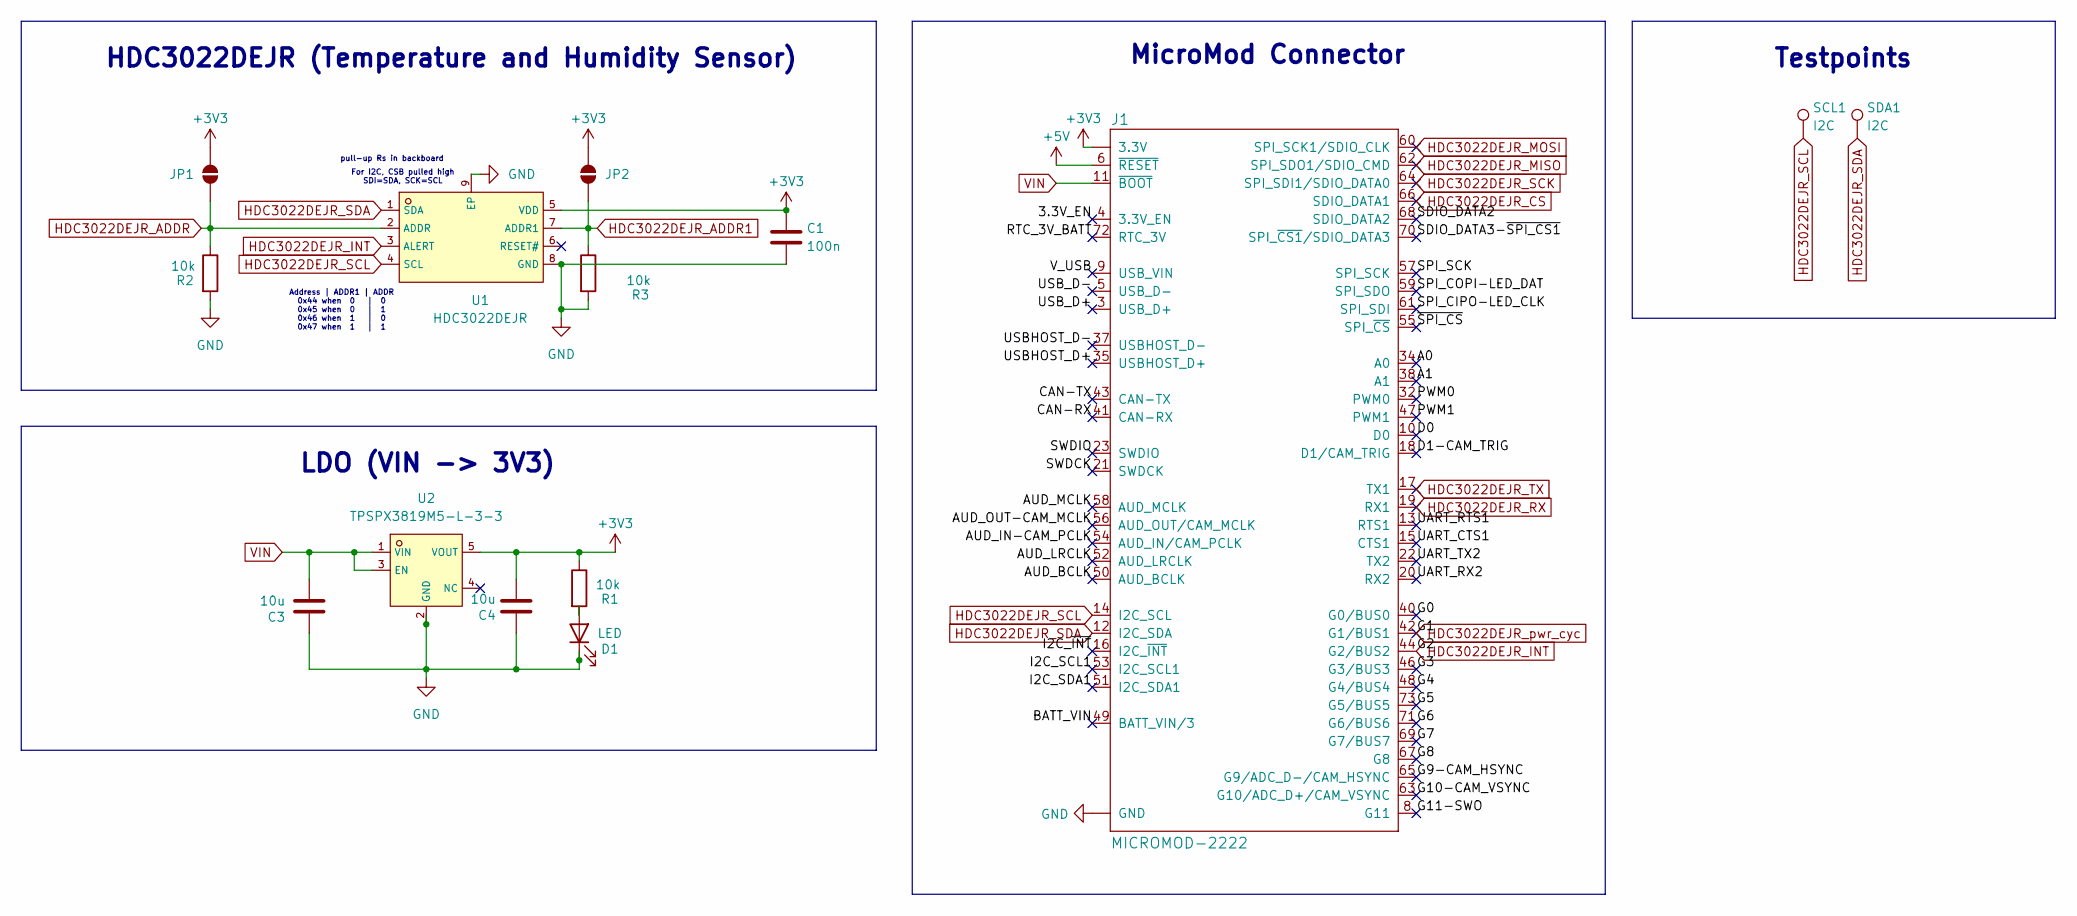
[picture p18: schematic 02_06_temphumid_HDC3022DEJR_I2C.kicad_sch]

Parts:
C1: 100n; C_0402_1005Metric
C3, C4: 10u; C_1206_3216Metric
D1: LED; LED_0603_1608Metric
J1: MICROMOD-2222; M.2-CARD-E-22
JP1, JP2: SolderJumper_2_Open; SolderJumper-2_P1.3mm_Open_Pad1.0x1.5mm
R1: 10k; R_0603_1608Metric
R2, R3: 10k; R_0402_1005Metric
SCL1: I2C; TestPoint_Pad_D1.0mm
SDA1: I2C; TestPoint_Pad_D1.0mm
U1: HDC3022DEJR; TDFN-8_L2.5-W2.5-P0.50-BL-EP; LCSC C17434731
U2: TPSPX3819M5-L-3-3; SOT-23-5_L3.0-W1.6-P0.95-LS2.8-BR; LCSC C5370980

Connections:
+3V3: C1.1, C4.1, J1.2 (3.3V), J1.74 (3.3V), JP1.2 (B), JP2.2 (B), R1.1, U1.5 (VDD), U2.5 (VOUT)
+5V: J1.6 (~RESET)
/3.3V_EN: J1.4 (3.3V_EN)
/A0: J1.34 (A0)
/A1: J1.38 (A1)
/AUD_BCLK: J1.50 (AUD_BCLK)
/AUD_IN-CAM_PCLK: J1.54 (AUD_IN/CAM_PCLK)
/AUD_LRCLK: J1.52 (AUD_LRCLK)
/AUD_MCLK: J1.58 (AUD_MCLK)
/AUD_OUT-CAM_MCLK: J1.56 (AUD_OUT/CAM_MCLK)
/BATT_VIN: J1.49 (BATT_VIN/3)
/CAN-RX: J1.41 (CAN-RX)
/CAN-TX: J1.43 (CAN-TX)
/D0: J1.10 (D0)
/D1-CAM_TRIG: J1.18 (D1/CAM_TRIG)
/G0: J1.40 (G0/BUS0)
/G3: J1.46 (G3/BUS3)
/G4: J1.48 (G4/BUS4)
/G5: J1.73 (G5/BUS5)
/G6: J1.71 (G6/BUS6)
/G7: J1.69 (G7/BUS7)
/G8: J1.67 (G8)
/G9-CAM_HSYNC: J1.65 (G9/ADC_D-/CAM_HSYNC)
/G10-CAM_VSYNC: J1.63 (G10/ADC_D+/CAM_VSYNC)
/G11-SWO: J1.8 (G11)
/I2C_SCL1: J1.53 (I2C_SCL1)
/I2C_SDA1: J1.51 (I2C_SDA1)
/I2C_~INT: J1.16 (I2C_~INT)
/PWM0: J1.32 (PWM0)
/PWM1: J1.47 (PWM1)
/RTC_3V_BATT: J1.72 (RTC_3V)
/SDIO_DATA2: J1.68 (SDIO_DATA2)
/SDIO_DATA3-~SPI_CS1: J1.70 (SPI_~CS1/SDIO_DATA3)
/SPI_CIPO-LED_CLK: J1.61 (SPI_SDI)
/SPI_COPI-LED_DAT: J1.59 (SPI_SDO)
/SPI_SCK: J1.57 (SPI_SCK)
/SWDCK: J1.21 (SWDCK)
/SWDIO: J1.23 (SWDIO)
/UART_CTS1: J1.15 (CTS1)
/UART_RTS1: J1.13 (RTS1)
/UART_RX2: J1.20 (RX2)
/UART_TX2: J1.22 (TX2)
/USBHOST_D+: J1.35 (USBHOST_D+)
/USBHOST_D-: J1.37 (USBHOST_D-)
/USB_D+: J1.3 (USB_D+)
/USB_D-: J1.5 (USB_D-)
/V_USB: J1.9 (USB_VIN)
/~SPI_CS: J1.55 (SPI_~CS)
GND: C1.2, C3.2, C4.2, D1.1 (K), J1.1 (GND), J1.7 (GND), J1.33 (GND), J1.36 (GND), J1.39 (GND), J1.45 (GND), J1.75 (GND), J1.GND1 (GND), J1.GND2 (GND), J1.GND3 (GND), R2.2, R3.2, U1.8 (GND), U1.9 (EP), U2.2 (GND)
HDC3022DEJR_ADDR: JP1.1 (A), R2.1, U1.2 (ADDR)
HDC3022DEJR_ADDR1: JP2.1 (A), R3.1, U1.7 (ADDR1)
HDC3022DEJR_CS: J1.66 (SDIO_DATA1)
HDC3022DEJR_INT: J1.44 (G2/BUS2), U1.3 (ALERT)
HDC3022DEJR_MISO: J1.62 (SPI_SDO1/SDIO_CMD)
HDC3022DEJR_MOSI: J1.60 (SPI_SCK1/SDIO_CLK)
HDC3022DEJR_RX: J1.19 (RX1)
HDC3022DEJR_SCK: J1.64 (SPI_SDI1/SDIO_DATA0)
HDC3022DEJR_SCL: J1.14 (I2C_SCL), SCL1.1, U1.4 (SCL)
HDC3022DEJR_SDA: J1.12 (I2C_SDA), SDA1.1, U1.1 (SDA)
HDC3022DEJR_TX: J1.17 (TX1)
HDC3022DEJR_pwr_cyc: J1.42 (G1/BUS1)
unnamed: D1.2 (A), R1.2
VIN: C3.1, J1.11 (~BOOT), U2.1 (VIN), U2.3 (EN)

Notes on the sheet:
Address | ADDR1 | ADDR 0x44 when 0 | 0 0x45 when 0 | 1 0x46 when 1 | 0 0x47 when 1 | 1
pull-up Rs in backboard
LDO (VIN -> 3V3)
For I2C, CSB pulled high SDI=SDA, SCK=SCL
MicroMod Connector
HDC3022DEJR (Temperature and Humidity Sensor)
Testpoints

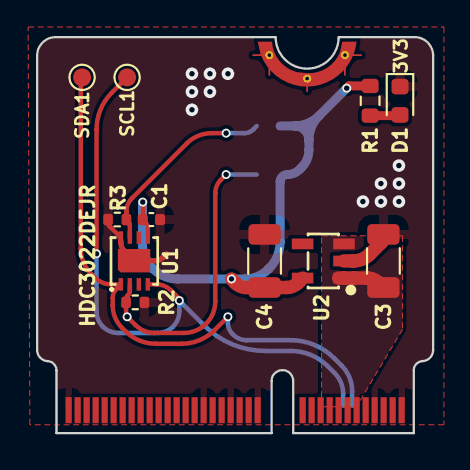
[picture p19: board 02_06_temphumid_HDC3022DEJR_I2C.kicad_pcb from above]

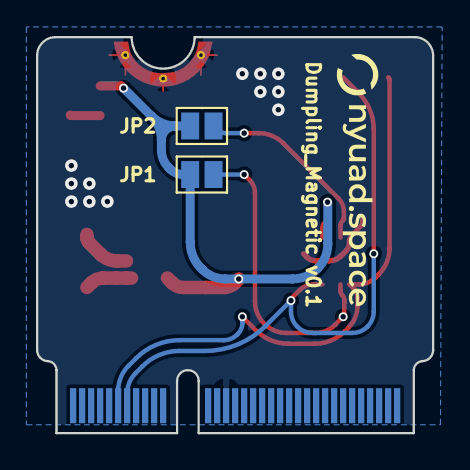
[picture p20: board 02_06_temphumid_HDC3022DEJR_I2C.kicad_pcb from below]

Board: 2 copper layers, 22.0 x 22.0 mm, 16 parts (2 on the bottom side), 9 nets.

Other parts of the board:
FRAME1: FRAME-LEDGER; CREATIVE_COMMONS
LOGO1: SPECIAL_INSTRUCTIONS-ORDERING; ORDERING_INSTRUCTIONS

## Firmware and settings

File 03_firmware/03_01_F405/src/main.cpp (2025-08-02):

#include "main.h"

void setup()
{

#if F405_DEBUG_MODE
  Serial.begin(115200);
  delay(100);
#endif

  // Initialize RGB LED
  neopixel.begin();
  neopixel.clear();
  neopixel.show();

  // Chip selects high
  // Must select chips manually!
  initialize_interboard_spi();
  initialize_mpu();

  // Trigger HIGH
  // Start logging data in circular buffer
  pinMode(LOG_TRIGGER_GPIO, OUTPUT);
  digitalWrite(LOG_TRIGGER_GPIO, HIGH);

#if F405_DEBUG_MODE
  Serial.println("Logging disabled.");
#endif

  // Build TX buffers
  dummy_packet_size = buildDummyRequest(dummy_buffer);
  command_packet_size = buildDataRequest(command_buffer);

  // Set initial color
  neopixel.setPixelColor(0, color_amber);
  neopixel.show();
}

void loop()
{

  switch (current_state)
  {
  case FLIGHT_READY_DETECTION:
  {
    // Check flight ready
    bool flight_ready = detect_flight_ready();

    // Change state on detect ready
    if (flight_ready)
    {
      // Change state
      current_state = FLIGHT_MONITORING;

      // Indicate
      neopixel.setPixelColor(0, color_green);
      neopixel.show();

#if F405_DEBUG_MODE
      Serial.println("Logging enabled!");
#endif
    }
    break;
  }

  case FLIGHT_MONITORING:
  {

    // Get continuous data
    sensors_event_t a, g, temp;
    mpu.getEvent(&a, &g, &temp);

    // Is the rocket upright?
    rocket_curr_upright = (abs(a.acceleration.y) > UPRIGHT_ACCEL_THRESH);

    // Upon motion detection
    if (mpu.getMotionInterruptStatus())
    {
      // Get data again
      // mpu.getEvent(&a, &g, &temp);

      // Compute total accel via squaring
      float totalAccel = sqrt(a.acceleration.x * a.acceleration.x +
                              a.acceleration.y * a.acceleration.y +
                              a.acceleration.z * a.acceleration.z);

// If no previous launch and significant accel
// Set launch
#if F405_DEBUG_MODE
      if (!launch_detected && totalAccel > DEBUG_LAUNCH_DETECT_ACCEL_THRESH)
#else
      if (!launch_detected && totalAccel > LAUNCH_DETECT_ACCEL_THRESH)
#endif
      {
        launch_detected = true;

        // Trigger GPIO low, write to main file
        digitalWrite(LOG_TRIGGER_GPIO, LOW);
#if F405_DEBUG_MODE
        Serial.println("Launch Detected! Wrote low to GPIO");
        Serial.print("Total accel: ");
        Serial.println(totalAccel);
#endif
      }

      // If motion detected and rocket already launched
      // Restart quiet timer
      // This will keep setting during flight
      if (launch_detected)
      {
        quiet_start_time = millis();
#if F405_DEBUG_MODE
        Serial.println("~~Flying~~");
        Serial.print("Total accel: ");
        Serial.println(totalAccel);
#endif
      }
    }

    // If launch detected and its been quiet
    if (launch_detected && (millis() - quiet_start_time > QUIET_TIME_THRESH_SEC))
    {

      // If rocket is still upright
      // Reset timer and reset launch detected because we are on pad
      if (rocket_curr_upright)
      {
        launch_detected = false;
        quiet_start_time = millis();
#if F405_DEBUG_MODE
        Serial.println("Still upright - resetting timer");
#endif
      }

      // Rocket is NOT upright
      else
      {
        // Change state
        current_state = DATA_COLLECTION;

        // Indicate
        neopixel.setPixelColor(0, color_blue);
        neopixel.show();
#if F405_DEBUG_MODE
        Serial.println("Flight ended. Logging disabled. Collecting logs now.");
#endif
      }
    }
    break;
  }

  case DATA_COLLECTION:
  {
    // TODO: put into for loop
    // Collect data from all coprocessors
    // make_data_request(INTERBOARD_SPI_CO1_CS);
    // make_data_request(INTERBOARD_SPI_CO2_CS);
    // store_to_sd(data);

    // Switch to new state
#if F405_DEBUG_MODE
    Serial.println();
    Serial.println("Data collection dummy. Standing by.");
#endif
    neopixel.setPixelColor(0, color_red);
    neopixel.show();
    current_state = STANDBY;
    break;
  }

  case STANDBY:
  {
    // NOTE: This delay is okay! Arbitrary number
    // The board will remain in this state unless restarted
    delay(10000);
    break;
  }
  }
}

void initialize_interboard_spi()
{
  // Initialize all CS pins as outputs (HIGH = inactive, safe default)
  for (size_t i = 0; i < InterboardSPI_CS::COUNT; i++)
  {
    pinMode(InterboardSPI_CS::PINS_LIST[i], OUTPUT);
    digitalWrite(InterboardSPI_CS::PINS_LIST[i], HIGH);
    Serial.print(InterboardSPI_CS::PINS_LIST[i]);
  }

  // Initialize SPI bus
  INTERBOARD_SPI.begin();
}

void initialize_mpu()
{
  if (!mpu.begin(MPU6050_I2CADDR_DEFAULT, &MPU_I2C))
  {
    Serial.println("Failed to find MPU6050 chip");
    while (1)
    {
      delay(10);
    }
  }

  // Setup motion detection
  mpu.setHighPassFilter(MPU6050_HIGHPASS_0_63_HZ);
  mpu.setMotionDetectionThreshold(1);
  mpu.setMotionDetectionDuration(MPU_MOT_DET_DUR);
  mpu.setInterruptPinLatch(true);
  mpu.setInterruptPinPolarity(true);
  mpu.setMotionInterrupt(true);
}

bool detect_flight_ready()
{
  // Only check if motion interrupt triggered
  if (mpu.getMotionInterruptStatus())
  {
    // Check if rocket is currently upright
    mpu.getEvent(&a, &g, &temp);
    rocket_curr_upright = (abs(a.acceleration.y) > UPRIGHT_ACCEL_THRESH);

    // If not upright anymore on new motion, reset upright tracker
    if (!rocket_curr_upright && rocket_prev_upright)
    {
#if F405_DEBUG_MODE
      Serial.println("Rocket no longer upright, resetting timer.");
#endif
      rocket_prev_upright = false;
    }

    // If just became upright, start timer and set upright tracker
    if (rocket_curr_upright && !rocket_prev_upright)
    {
      upright_start_time = millis();
      rocket_prev_upright = true;
#if F405_DEBUG_MODE
      Serial.println("Rocket became upright, starting timer.");
#endif
    }
  }

  // Check timer
  // Switch state past threshold
  if (rocket_prev_upright && (millis() - upright_start_time > UPRIGHT_TIME_THRESH_SEC))
  {
#if F405_DEBUG_MODE
    Serial.println("Rocket upright threshold met, switching to flight monitoring.");
#endif
    return true;
  }

  // Blink LED when timer is running
  if (rocket_prev_upright)
  {
    if (millis() - led_blink_time > 500)
    {
      led_blink_state = !led_blink_state;
      led_blink_time = millis();

      if (led_blink_state)
      {
        neopixel.setPixelColor(0, color_amber);
      }
      else
      {
        neopixel.clear();
      }
      neopixel.show();
    }
  }
  else
  {
    neopixel.setPixelColor(0, neopixel.Color(255, 191, 0));
    neopixel.show();
  }

  return false;
}

bool make_data_request(uint8_t CS_PIN)
{
  // Send initial command packet
  digitalWrite(CS_PIN, LOW);
  INTERBOARD_SPI.transfer(command_buffer, rx_buffer, command_packet_size, SPI_LAST);
  digitalWrite(CS_PIN, HIGH);

#if F405_DEBUG_MODE
  _print_buffer("TX", command_buffer, command_packet_size);
  _print_buffer("RX", rx_buffer, command_packet_size);
#endif

  // Delay to allow coprocessor to prepare data.
  delay(PACKET_PREP_TIME);

  // Poll for response data with a timeout
  unsigned long start_time = millis();
  while (millis() - start_time < POLLING_TIMEOUT_MS)
  {
    digitalWrite(CS_PIN, LOW);
    delay(5);
    INTERBOARD_SPI.transfer(dummy_buffer, rx_buffer, dummy_packet_size, SPI_LAST);
    digitalWrite(CS_PIN, HIGH);

#if F405_DEBUG_MODE
    _print_buffer("TX", dummy_buffer, 5);
    _print_buffer("RX", rx_buffer, MAX_PACKET_SIZE);
#endif

    if (check_end_sequence(rx_buffer))
    {
      Serial.println("Got end sequence!");
      return true;
    }

    // Delay before next poll
    delay(1000);
  }

  return false; // Timeout
}

bool check_end_sequence(uint8_t *buffer)
{
  return (buffer[0] == 0xBE && buffer[1] == 0xEF);
}

void _print_buffer(const char *label, uint8_t *buffer, uint8_t size)
{
  Serial.print("Packet size: ");
  Serial.print(size);
  Serial.print(" | ");
  Serial.print(label);
  Serial.print(" Buffer: ");
  for (int i = 0; i < size; i++)
  {
    Serial.print("0x");
    if (buffer[i] < 16)
      Serial.print("0");
    Serial.print(buffer[i], HEX);
    Serial.print(" ");
  }
  Serial.println();
}

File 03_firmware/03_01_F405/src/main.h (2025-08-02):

#pragma once
#include "Arduino.h"
#include "SPI.h"
#include "Wire.h"
#include "pinout.h"
#include "Adafruit_NeoPixel.h"
#include "SPIPacket.h"
#include "Adafruit_MPU6050.h"

#include "comm.h"

/*******************************/
/*******************************/
/*******************************/

// F405_DEBUG_MODE
#define F405_DEBUG_MODE 1

// Flight ready detection
#define UPRIGHT_ACCEL_THRESH 7.5
#define UPRIGHT_TIME_THRESH_SEC 60000
#define MPU_MOT_DET_DUR 5

// Flight end detection
#define QUIET_TIME_THRESH_SEC 60000
#define LAUNCH_DETECT_ACCEL_THRESH 30
#define DEBUG_LAUNCH_DETECT_ACCEL_THRESH 15

// Data collection
#define PACKET_PREP_TIME 10000
#define POLLING_TIMEOUT_MS 60000

/*******************************/
/*******************************/
/*******************************/

// Interboard SPI chip selects
namespace InterboardSPI_CS
{
  constexpr uint32_t PINS_LIST[] = {INTERBOARD_SPI_CO1_CS,
                                    INTERBOARD_SPI_CO2_CS,
                                    INTERBOARD_SPI_CO3_CS,
                                    INTERBOARD_SPI_CO4_CS,
                                    INTERBOARD_SPI_CO5_CS,
                                    INTERBOARD_SPI_CO6_CS};

  constexpr size_t COUNT = sizeof(PINS_LIST) / sizeof(PINS_LIST[0]);
}

/*******************************/
/*******************************/
/*******************************/

// LED
Adafruit_NeoPixel neopixel(1, RGB_LED, NEO_GRB + NEO_KHZ800);

// Comms
SPIClass INTERBOARD_SPI = SPIClass(INTERBOARD_SPI_MOSI, INTERBOARD_SPI_MISO, INTERBOARD_SPI_SCK);
TwoWire MPU_I2C(MPU_SDA, MPU_SCL);

// IMU
Adafruit_MPU6050 mpu;
sensors_event_t a, g, temp;

/*******************************/
/*******************************/
/*******************************/

// Flight states
enum FlightState
{
  FLIGHT_READY_DETECTION,
  FLIGHT_MONITORING,
  DATA_COLLECTION,
  STANDBY
};
FlightState current_state = FLIGHT_READY_DETECTION;
FlightState previous_state = STANDBY;

// LED indication
uint32_t color_red = neopixel.Color(200, 0, 0);
uint32_t color_amber = neopixel.Color(220, 160, 0);
uint32_t color_green = neopixel.Color(0, 160, 0);
uint32_t color_blue = neopixel.Color(0, 0, 100);

unsigned long led_blink_time = 0;
bool led_blink_state = false;

// Flight ready variables
bool rocket_curr_upright = false;
bool rocket_prev_upright = false;
unsigned long upright_start_time = 0;

// Flight end variables
bool launch_detected = false;
bool first_entry = true;
unsigned long quiet_start_time = 0;

// SPI communication
uint8_t rx_buffer[MAX_PACKET_SIZE];

uint8_t command_buffer[MAX_PACKET_SIZE];
uint8_t command_packet_size = 0;

uint8_t dummy_buffer[MAX_PACKET_SIZE];
uint8_t dummy_packet_size = 0;

// Function declarations
void initialize_interboard_spi();
void initialize_mpu();
bool detect_flight_ready();

bool make_data_request(uint8_t);
bool check_end_sequence(uint8_t *);
void _print_buffer(const char *, uint8_t *, uint8_t);

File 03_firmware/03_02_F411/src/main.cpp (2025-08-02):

#include "main.h"

void setup()
{

    // ** Run SdFat_format to reset flash to clearn state when actual flight **

#if F411_DEBUG_MODE
    Serial.begin(115200);
    delay(2000);

#endif

    // Setup logging interrupts pins
    pinMode(LOG_TRIGGER_GPIO, INPUT);
    attachInterrupt(digitalPinToInterrupt(LOG_TRIGGER_GPIO), LOG_TRIGGER_ISR, RISING);

    logging_allowed = true;
    logging_circular = true;
    entered_circular_mode = false;
    entered_regular_mode = false;

    // Clear LED
    neopixel.begin();
    neopixel.clear();
    neopixel.show();
    neopixel.setBrightness(30); // Dim it down!

    // Discover and configure sensor
    String s = detectSensor();
    logStatus("Connected to: %s", s.c_str());
#if F411_DEBUG_MODE
    Serial.print("Connected to: ");
    Serial.println(s);
#endif

    // Catch bad initialization
    success_flag_1 = initSensorComm(detectedSensor);
    logStatus("Sensor communication set.");
#if F411_DEBUG_MODE
    Serial.println("Sensor communication set.");
#endif

    configSensor(detectedSensor);
    logStatus("Sensor configured.");

#if F411_DEBUG_MODE
    Serial.println("Sensor configured.");
#endif

    // Setup flash
    regularStorageFull = false; // Storage status tracking
    success_flag_2 = flash_memory.begin();
    success_flag_3 = initFlashWrite();

    // Create headers and open file
    initFilesForSensor(detectedSensor);
    // Create file for logging
    initFileForStatus();

    // Access all file info with this object
    SensorFileInfo info = getSensorFileInfo(detectedSensor);

#if F411_DEBUG_MODE
    uint32_t jedec_id = flash_memory.getJEDECID();
    Serial.print("JEDEC ID: 0x");
    Serial.println(jedec_id, HEX);
    Serial.print("Flash size (usable): ");
    Serial.print(flash_memory.size() / 1024);
    Serial.println(" KB");
    Serial.print("Circular file name: ");
    Serial.println(info.circularName);
    Serial.print("Circular file size (bytes): ");
    Serial.println(getFileSize(info.circularName));
    Serial.print("Regular file name: ");
    Serial.println(info.regularName);
    Serial.print("Regular file size (bytes): ");
    Serial.println(getFileSize(info.regularName));
    Serial.print("\n");
#endif
    logStatus("JEDEC ID: 0x%X", jedec_id);
    logStatus("Flash size (usable): %u KB", flash_memory.size() / 1024);
    logStatus("Circular file name: %s", info.circularName);
    logStatus("Circular file size (bytes): %u", getFileSize(info.circularName));
    logStatus("Regular file name: %s", info.regularName);
    logStatus("Regular file size (bytes): %u", getFileSize(info.regularName));

    if (!success_flag_1 || !success_flag_2 || !success_flag_2 || detectedSensor == SENSOR_UNKNOWN)
    {
#if F411_DEBUG_MODE
        Serial.println("Sensor init failed!");
#endif
        while (1)
        {
            _blink_red();
        }
    }
    neopixel.setPixelColor(0, color_amber);
    neopixel.show();

// READ FROM FLASH MODE
#if READ_FROM_FLASH
    // CIRCUALAR
    // Re-open the file for reading
    File32 circFile = fatfs.open(info.circularName, FILE_READ);

    // Display what is inside files
    if (circFile)
    {
#if F411_DEBUG_MODE
        Serial.print("Circular file size: ");
        Serial.println(circFile.size());
        Serial.println("Reading content of circular file:");
#endif

        // read from the file until there's nothing else in it
        while (circFile.available())
        {
            Serial.write(circFile.read());
        }
        // close the file
        circFile.close();
    }
    else
    {
#if F411_DEBUG_MODE
        Serial.println("error opening circular file");
#endif
    }

    // REGULAR
    File32 regFile = fatfs.open(info.regularName, FILE_READ);
    if (regFile)
    {
#if F411_DEBUG_MODE
        Serial.println("\nReading content of regular file:");
#endif

        // read from the file until there's nothing else in it
        while (regFile.available())
        {
            Serial.write(regFile.read());
        }
#if F411_DEBUG_MODE
        Serial.println("--- End of regular file reached ---");
#endif
        // close the file
        regFile.close();
    }
    else
    {
#if F411_DEBUG_MODE
        Serial.println("error opening regular file");
#endif
    }
    // STATUS
    File32 statFile = fatfs.open("status.txt", FILE_READ);
    if (statFile)
    {
#if F411_DEBUG_MODE
        Serial.println("\n== Reading content of status file == \n");
#endif

        // read from the file until there's nothing else in it
        while (statFile.available())
        {
            Serial.write(statFile.read());
        }
#if F411_DEBUG_MODE
        Serial.println("--- End of status file reached ---");
#endif
        // close the file
        statFile.close();
    }
    else
    {
#if F411_DEBUG_MODE
        Serial.println("error opening status file");
#endif
    }

#endif
}

void loop()
{
    // Tracking status flush
    static unsigned long lastStatusFlush = 0;
    static int flushCounter = 0;
    static bool final_status_logged = false;
    static bool was_circular = false;

    // Handle circular mode entry
    if (entered_circular_mode)
    {
        entered_circular_mode = false; // Clear flag
        // logStatusTimed(millis(), "High pin. Logging in circular file.");
    }

    // Handle regular mode entry (final message)
    if (entered_regular_mode)
    {
        entered_regular_mode = false; // Clear flag
        logStatusTimed(millis(), "Low pin. Logging in main file.");
        flushStatusToFile();
        final_status_logged = true;
    }

// WRITE TO FLASH MODE
#if WRITE_TO_FLASH
    // Only log when allowed and regular storage has space
    if (logging_allowed && !regularStorageFull)
    {
        // Read sensor + Write to flash in circular/regular buffer
        readSensor(detectedSensor, logging_circular);

        // Periodic flushes until final message
        if (!final_status_logged && logging_circular)
        {
            // Use the delay period for occasional status flushing (circular mode only)
            flushCounter++;
            if (flushCounter >= 1200) // Every ~1 minute
            {
                unsigned long flushStart = millis();
                flushStatusToFile();
                unsigned long flushTime = millis() - flushStart;

                // Adjust remaining delay to maintain timing
                int remainingDelay = 50 - flushTime;
                if (remainingDelay > 0)
                {
                    delay(remainingDelay);
                }

                flushCounter = 0;
            }
            else
            {
                delay(50); // Normal delay
            }
        }
        else
        {
            delay(50); // Normal delay, no more status logging
        }
        // TODO: LED indication for circular/ regular logging etc.
    }
#endif
}
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

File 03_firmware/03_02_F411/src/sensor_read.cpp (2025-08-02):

#include "sensor_read.h"

#define SEALEVELPRESSURE_HPA (1013.25)

// Time buffer
unsigned long previousMillis = 0; // store last updated time
const long interval = 10;         // interval at which to delay (milliseconds)

// == readings for each sensors ==

void read_LSM6DS()
{
    // true if new data available to read
    if (!lsm6ds_accel_gyro.accelerationAvailable() || !lsm6ds_accel_gyro.gyroscopeAvailable())
    {
        return;
    }
    // Read sensor data (Accel: m/s^2, Gyro: rad/s) to three decimals
    float x, y, z, temp;
    sensors_event_t temp_event;

    lsm6ds_accel_gyro.readAcceleration(x, y, z);
    accel_x_read = roundf(x * 1000) / 1000.0f;
    accel_y_read = roundf(y * 1000) / 1000.0f;
    accel_z_read = roundf(z * 1000) / 1000.0f;

    lsm6ds_accel_gyro.readGyroscope(x, y, z);
    gyro_x_read = roundf(x * 1000) / 1000.0f;
    gyro_y_read = roundf(y * 1000) / 1000.0f;
    gyro_z_read = roundf(z * 1000) / 1000.0f;

    lsm6ds_accel_gyro.getEvent(NULL, NULL, &temp_event);
    temp_read = roundf(temp_event.temperature * 1000) / 1000.0f;

#if F411_DEBUG_MODE
    // Timestamp
    Serial.print(millis());
    Serial.print("ms, T: ");
    // Display on Serial (Timestamp done internally)
    Serial.print("Accel X: ");
    Serial.print(accel_x_read);
    Serial.print(" Accel Y: ");
    Serial.print(accel_y_read);
    Serial.print(" Accel Z: ");
    Serial.print(accel_z_read);
    Serial.print(" Gyro X: ");
    Serial.print(gyro_x_read);
    Serial.print(" Gyro Y: ");
    Serial.print(gyro_y_read);
    Serial.print(" Gyro Z: ");
    Serial.print(gyro_z_read);
    Serial.print(" T: ");
    Serial.println(temp_read);
#endif
}
void read_DPS310()
{
    // true if new data available to read
    if (!dps310_baro_temp.temperatureAvailable() || !dps310_baro_temp.pressureAvailable())
    {
        return;
    }
    // Read sensor data (Temp: *C, Pressure: hPa) to three decimals
    sensors_event_t temp_event, pressure_event;
    dps310_baro_temp.getEvents(&temp_event, &pressure_event);
    temp_read = roundf(temp_event.temperature * 1000) / 1000.0f;
    press_read = roundf(pressure_event.pressure * 1000) / 1000.0f;

#if F411_DEBUG_MODE
    // Timestamp
    Serial.print(millis());
    Serial.print("ms, T: ");

    // Display on Serial
    Serial.print(temp_read);
    Serial.print("*C, P: ");
    Serial.print(press_read);
    Serial.println("hPa");
#endif
}
void read_BMI088()
{
    // availability checker not supported

    // Read sensor data (Accel: m/ss, Gyro: rad/s) to three decimals
    bmi088_accel.readSensor();
    bmi088_gyro.readSensor();

    accel_x_read = roundf(bmi088_accel.getAccelX_mss() * 1000) / 1000.0f;
    accel_y_read = roundf(bmi088_accel.getAccelY_mss() * 1000) / 1000.0f;
    accel_z_read = roundf(bmi088_accel.getAccelZ_mss() * 1000) / 1000.0f;
    gyro_x_read = roundf(bmi088_gyro.getGyroX_rads() * 1000) / 1000.0f;
    gyro_y_read = roundf(bmi088_gyro.getGyroY_rads() * 1000) / 1000.0f;
    gyro_z_read = roundf(bmi088_gyro.getGyroZ_rads() * 1000) / 1000.0f;
    temp_read = roundf(bmi088_accel.getTemperature_C() * 1000) / 1000.0f;

#if F411_DEBUG_MODE
    // Timestamp
    Serial.print(millis());
    Serial.print("ms, T: ");

    // Display on Serial
    Serial.print(accel_x_read);
    Serial.print("\t");
    Serial.print(accel_y_read);
    Serial.print("\t");
    Serial.print(accel_z_read);
    Serial.print("\t");
    Serial.print(gyro_x_read);
    Serial.print("\t");
    Serial.print(gyro_y_read);
    Serial.print("\t");
    Serial.print(gyro_z_read);
    Serial.print("\t");
    Serial.print(temp_read);
    Serial.print("\n");
#endif
}
void read_BMP390()
{
    // availability checker not supported

    // Read sensor data (Temp: *C, Pressure: hPa) to three decimals
    bmp390_baro.performReading();
    temp_read = roundf(bmp390_baro.temperature * 1000) / 1000.0f;
    press_read = roundf(bmp390_baro.pressure * 1000) / 1000.0f;
    bmp390_alt_read = roundf(bmp390_baro.readAltitude(SEALEVELPRESSURE_HPA) * 1000) / 1000.0f;

#if F411_DEBUG_MODE
    // Timestamp
    Serial.print(millis());
    Serial.print("ms, T: ");

    // Display on Serial
    Serial.print(temp_read);
    Serial.print("*C, P: ");
    Serial.print(press_read);
    Serial.print("hPa");
    Serial.print(bmp390_alt_read);
    Serial.println("m");
#endif
}
void read_LIS2MDL()
{
    // availability checker not supported

    // Read sensor data (Magnetic vector: uT) to three decimals
    sensors_event_t mag_event;
    lis2mdl_mag.getEvent(&mag_event);

    mag_x_read = roundf(mag_event.magnetic.x * 1000) / 1000.0f;
    mag_y_read = roundf(mag_event.magnetic.y * 1000) / 1000.0f;
    mag_z_read = roundf(mag_event.magnetic.z * 1000) / 1000.0f;

#if F411_DEBUG_MODE
    // Timestamp
    Serial.print(millis());
    Serial.print("ms, T: ");

    // Display on Serial
    Serial.print("X: ");
    Serial.print(mag_x_read);
    Serial.print("  ");
    Serial.print("Y: ");
    Serial.print(mag_y_read);
    Serial.print("  ");
    Serial.print("Z: ");
    Serial.print(mag_z_read);
    Serial.print("  ");
    Serial.println("uT");
#endif
}
void read_HDC302()
{
    double temp = 0.0;
    double RH = 0.0;

    // availability checker not supported

    // perform a 'forced' reading every second if not in automatic mode
    if (hdc302_temp_hum.getAutoMode() == EXIT_AUTO_MODE)
    {
        if (!hdc302_temp_hum.readTemperatureHumidityOnDemand(temp, RH, TRIGGERMODE_LP0))
        {
            Serial.println("Failed to read temperature and humidity.");
            return;
        }
        delay(1000);
    }
    else
    {
        if (!hdc302_temp_hum.readAutoTempRH(temp, RH))
        {
            // Data not ready for reading, silently retry later
            return;
        }
    }

    // Read sensor data (Relative humidity: %, Temperature: *C) to three decimals
    temp_read = roundf(temp * 1000) / 1000.0f;
    hum_read = roundf(RH * 1000) / 1000.0f;

#if F411_DEBUG_MODE
    // Timestamp
    Serial.print(millis());
    Serial.print("ms,");

    // Display on Serial
    Serial.print(" RH: ");
    Serial.print(hum_read);
    Serial.print(", T: ");
    Serial.print(temp_read);
    Serial.print("\n");
#endif
}
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

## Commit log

2024-11-28 changed folder structure
    [sensor-board.kicad_pcb, sensor-board.kicad_sch]
2025-01-21 added mcu
    [main-board.kicad_sch]
2025-01-22 Added supporting circuitry
    [main-board.kicad_sch, untitled.kicad_sch]
2025-03-10 added coprocessors
    [Dumpling_Main.kicad_pcb, Dumpling_Main.kicad_sch, connectors_sch.kicad_sch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]
2025-03-10 dumped stuff away
    [main-board.kicad_pcb, main-board.kicad_sch, peripherals.kicad_sch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]
2025-03-19 power routing
    [Dumpling_Main.kicad_sch, coprocessor_1.kicad_sch, coprocessor_2.kicad_sch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]
2025-03-31 wiring fin, pre-drc
    [Dumpling_Main.kicad_pcb, Dumpling_Main.kicad_sch]
2025-05-07 ebay backboard
    [Dumpling_Main-CuBottom.gbr, Dumpling_Main-CuIn1.gbr, Dumpling_Main-CuIn2.gbr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]
2025-05-09 deleted files
    [Ebay-CuBottom.gbr, Ebay-CuTop.gbr, Ebay-EdgeCuts.gbr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]
2025-05-22 Added six sensorboards
    [02_01_sensor_IMU-CuBottom.gbr, 02_01_sensor_IMU-CuTop.gbr, 02_01_sensor_IMU-EdgeCuts.gbr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]
2025-05-27 filled missing connections :/
    [02_01_sensor_IMU_LSM6DSO32-CuBottom.gbr, 02_01_sensor_IMU_LSM6DSO32-CuTop.gbr, 02_01_sensor_IMU_LSM6DSO32-EdgeCuts.gbr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]
2025-05-27 schematic pdf
2025-05-30 schematic update
2025-05-31 detect sensor, read sensor, write to local flash
2025-06-02 sensor config
    [02_05_magnetometer_LIS2MDLTR_I2C.kicad_sch]
2025-06-02 log sensor
2025-06-05 sensor detection works
2025-06-06 sensor detect (w/o HDC302)
2025-06-06 Functioning sensor detect
2025-06-06 Revert "heartbeat with error"
    This reverts commit fa3044730102aa221b6a0c8ac8d58779b8e22936.
    [globals.cpp, main.cpp, main.h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]
2025-06-07 Refactor sensor detect, don't use global objects
2025-06-08 Naming fix + remove includes
    [globals.cpp, main.h]
2025-06-08 Fix BMI CS names
    [globals.cpp, pinout.h]
2025-06-08 Working comm init and sensor config
2025-06-08 Working SPI slave mode for coprocessor
2025-06-08 FIx SPI bus contention
    [pinout.h]
2025-06-09 reads sensors
2025-06-09 sensor_read better format
2025-06-09 sensor read cleanup
2025-06-09 remove timestamp print
2025-06-09 variable name mismatch fix
    [sensor_read.cpp]
2025-06-09 serial print added
2025-06-09 write sensor to flash (with errors)
    [main.cpp, main.h]
2025-06-10 sensor_read format cleanup
2025-06-10 Flash write synced with sensor read
2025-06-11 read from flash by chunks (with error)
    [flash_write_read.cpp, main.cpp, sensor_config.cpp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]
2025-06-11 minor fix + debug macro
    [flash_write_read.cpp, main.cpp, sensor_read.cpp]
2025-06-11 Fix input pullup state mistake
    [main.cpp]
2025-06-11 Blink red on init failures
    [flash_write_read.cpp, main.cpp, main.h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]
2025-06-12 change debug macro names, FAILING SPI comm
    [flash_write_read.cpp, main.cpp, main.h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]
2025-06-12 Make data collection dummy, skip it.
    [main.cpp]
2025-06-15 up to stage fright flight
2025-06-16 error in initializing/opening file
    [flash_write_read.cpp, main.cpp]
2025-06-22 added F411 LED
2025-06-22 adjusted sensor config details + added status log statements
2025-08-02 added board renderings
2026-06-09 added minimal LSM6DS + flash drivers
2026-06-10 added buildflag + verified one sensor log/dump pipeline

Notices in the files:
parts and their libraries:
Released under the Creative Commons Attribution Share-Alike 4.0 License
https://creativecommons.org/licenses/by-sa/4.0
